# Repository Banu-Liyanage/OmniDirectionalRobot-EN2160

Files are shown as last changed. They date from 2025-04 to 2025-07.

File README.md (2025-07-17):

# 🤖 Omni Directional Robot Platform - EN2160

<div align="center">


<br>
<!-- [![University](https://img.shields.io/badge/University%20of-Moratuwa-red?style=for-the-badge&logo=university&logoColor=white)](https://uom.lk)
[![Course](https://img.shields.io/badge/Course-EN2160-orange?style=for-the-badge&logo=academic&logoColor=white)]()
[![License](https://img.shields.io/badge/License-MIT-green?style=for-the-badge&logo=opensource&logoColor=white)]() -->

</div>

---

## 🌟 Project Vision

**Revolutionizing Indoor Automation Through Intelligent Omnidirectional Mobility**

This repository showcases the design and development of an **Omni Directional Robot Platform** engineered as part of the **EN2160: Electronic Design Realization Module** at the University of Moratuwa. 

Our mission is to create a **highly maneuverable, precise, and intelligent robotic platform** capable of navigating complex indoor environments with ease. 

This project shows how we apply theoretical concepts from electronics and control systems to build a practical solution that meets real-world challenges in automation and robotics.

This is an on-going project, where we are currently working on the Robot's Firmware and Control systems. The hardware is already completed and tested.

<div align="center">
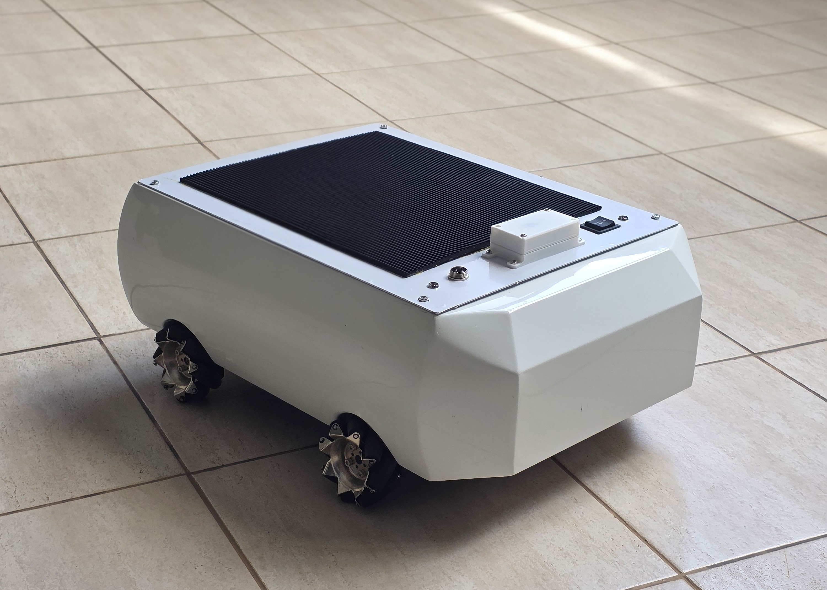
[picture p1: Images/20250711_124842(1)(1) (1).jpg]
  
</div>

---

## 🎯 Project Objectives

<div align="center">

| 🎪 **Mecanum Wheel Kinematics** | 🧠 **Intelligent Positioning** | ⚙️ **Precision Control** |
|:---:|:---:|:---:|
| 4-wheel Mecanum platform for unrestricted motion | Advanced position estimation algorithms | Real-time wheel control with sub-millimeter accuracy |

</div>

---

<!-- ## 🛠️ Revolutionary Features

### 🎯 **Core Capabilities**

| Feature | Description | Status |
|:---:|:---|:---:|
| ✅ **Mecanum Wheel Mastery** | Advanced 4-wheel omnidirectional locomotion system | 🟢 **Complete** |
| ✅ **Multi-MCU Architecture** | Distributed processing with dedicated motor controllers | 🟢 **Complete** |
| ✅ **Precision Sensing Suite** | IMU-based orientation tracking and sensor fusion | 🟢 **Complete** |
| ✅ **Wireless Command Center** | Bluetooth connectivity with intuitive GUI control | 🟢 **Complete** |
| ✅ **Robust Communication** | RS485 differential signaling for noise immunity | 🟢 **Complete** |
| ✅ **Modular PCB Design** | Custom-engineered boards for power, logic, and motor control | 🟢 **Complete** |
| ✅ **Real-Time Diagnostics** | Live telemetry and system health monitoring | 🟢 **Complete** |
| ✅ **Industrial Aesthetics** | Professional-grade chassis with automotive paint finish | 🟢 **Complete** | -->

<div align="center">

<!-- Add feature showcase images here -->

<table>
<tr>
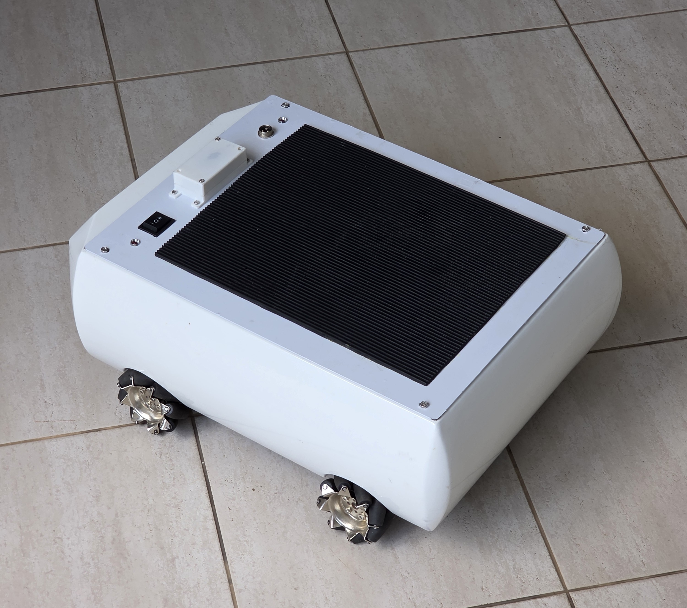
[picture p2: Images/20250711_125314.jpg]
Complete Robot
<td align="center"><br><b>Complete Assembly</b></td>
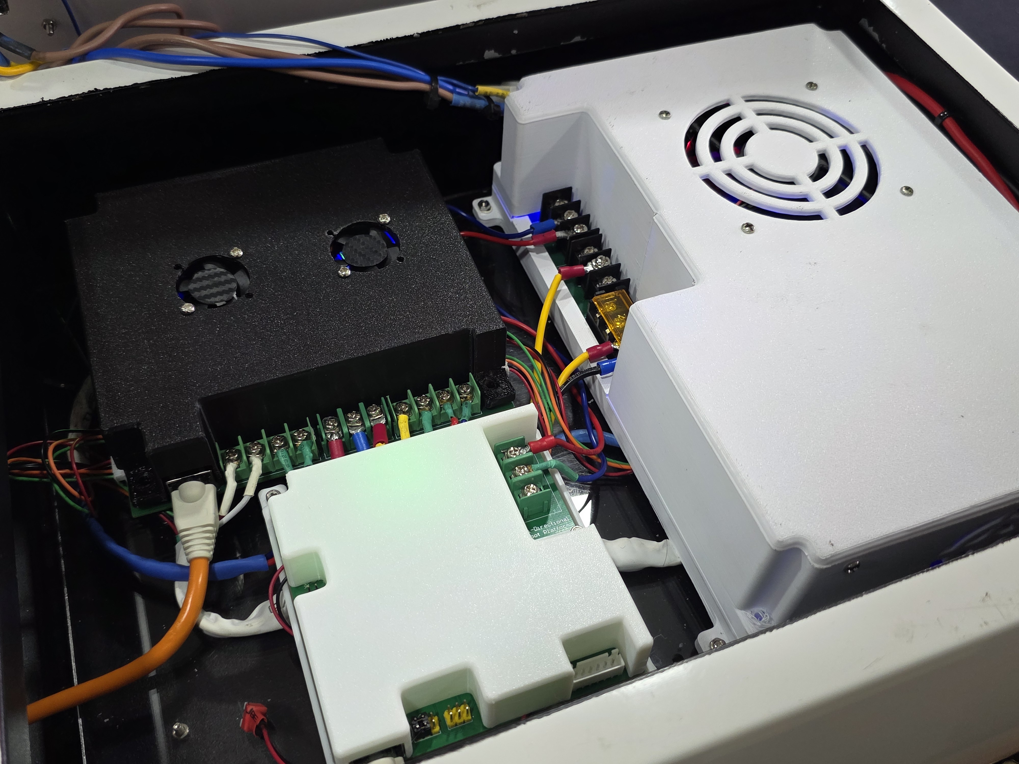
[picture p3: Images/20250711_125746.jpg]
Enclosure
<td align="center"><br><b>Internal view</b></td>

</tr>
</table>

</div>

---

## 🔌 Electronic Systems

<!-- ### 📋 **PCB Module Ecosystem** -->

<div align="center">

<!-- Add PCB images here -->
<table>
<tr>
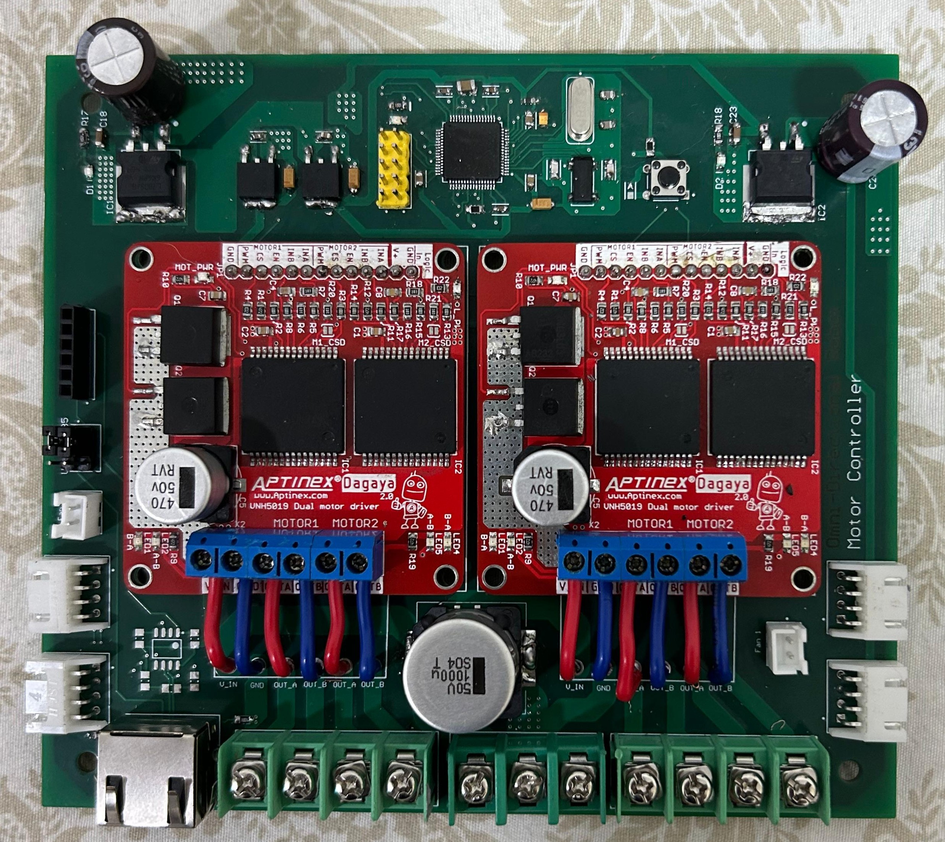
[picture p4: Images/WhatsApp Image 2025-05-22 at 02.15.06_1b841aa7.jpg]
Electronics
<td align="center"><br><b>Motor Controller PCB</b></td>
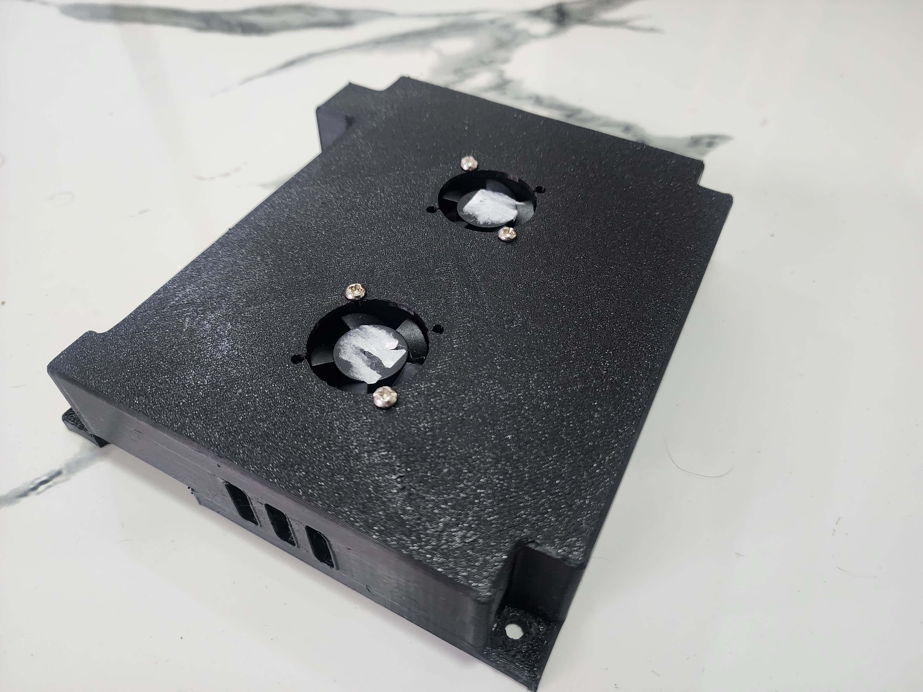
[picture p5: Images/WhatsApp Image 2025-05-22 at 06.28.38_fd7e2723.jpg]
Drive System
<td align="center"><br><b>Motor Controller Enclosure</b></td>

</tr>
<tr>
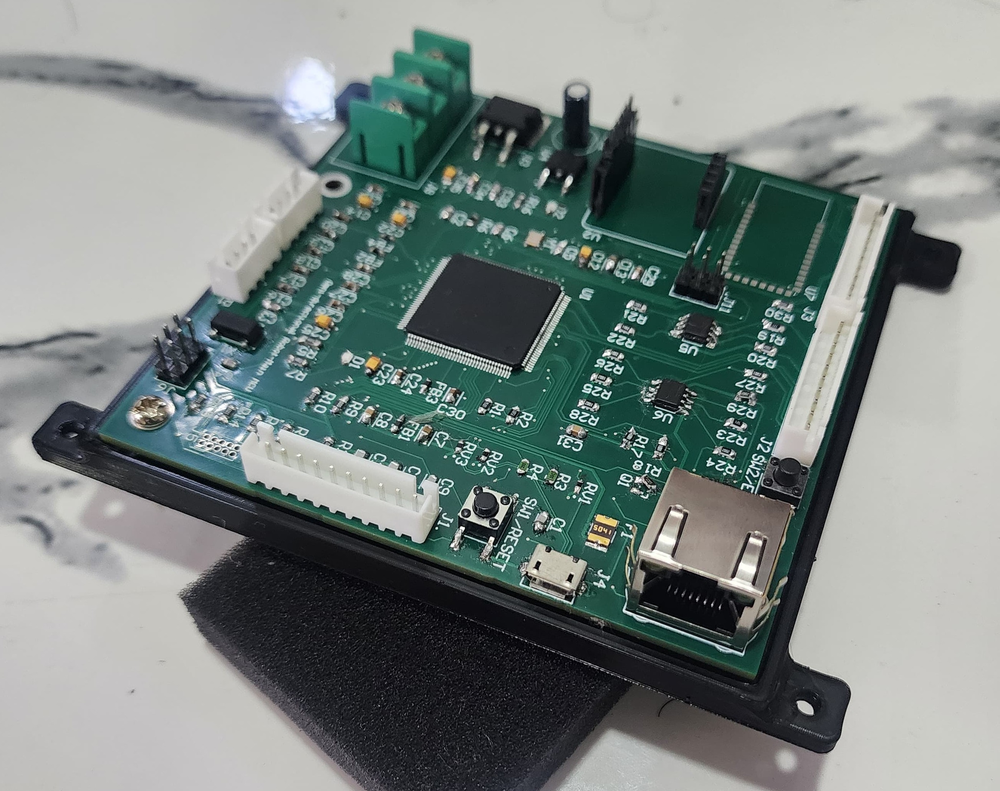
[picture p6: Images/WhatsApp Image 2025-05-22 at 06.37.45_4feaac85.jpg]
Controller
<td align="center"><br><b>Main Controller PCB</b></td>
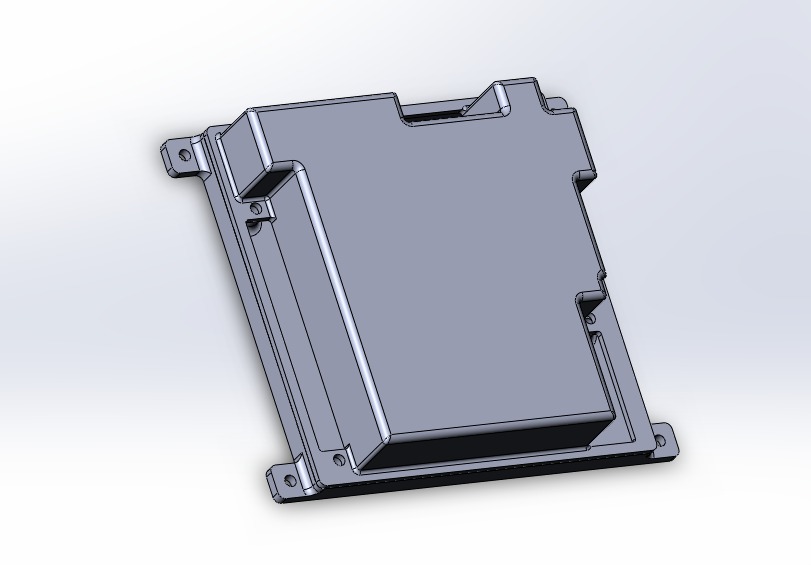
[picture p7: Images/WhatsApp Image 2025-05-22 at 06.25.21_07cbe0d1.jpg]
Motors
<td align="center"><br><b>Main Controller Enclosure</b></td>
</tr>
</table>
</div>

| **PCB Module** | **Function** | **Key Features** |
|:---:|:---|:---|
| 🔋 **Power Distribution** | Multi-rail power management | Fuse protection, LED diagnostics, screw terminals |
| 🧠 **Main Controller** | System coordination and communication | 4-layer design, SAM3X8E, BNO055, HC-05 integration |
| ⚡ **Motor Controller** | Real-time motor drive and feedback | STM32F446RE, VNH5019 drivers, RS485 communication |

<!-- ### 🛡️ **Safety & Protection Systems**

- **20A Master Fuse** with branch-specific protection (2A-15A)
- **Thermal Management** with active cooling consideration
- **Overcurrent Protection** at component and system levels
- **EMI Mitigation** through differential signaling and proper grounding

--- -->

---

### 🏗️ **System Architecture**

<div align="center">

<!-- Add system architecture diagram here -->

</div>

### ⚡ **Hardware Specifications**

| **Component** | **Selection** | **Performance** |
|:---:|:---:|:---:|
| 🧠 **Main MCU** | SAM3X8E | 84 MHz Cortex-M3 |
| 🎮 **Motor Controller** | STM32F446RE | 180 MHz, Real-time loops |
| 🔋 **Drive Motors** | 24V 5Nm Planetary Gear | 1:100 ratio, 120 RPM |
| 🧭 **Navigation IMU** | Bosch BNO055 | 9-DOF sensor fusion |
| ⚡ **Motor Drivers** | VNH5019 H-Bridge | 30A peak current |
| 🎯 **Mecanum Wheels** | Metal-core construction | Omnidirectional mobility |
| 🔌 **Power System** | 12V battery + regulation | Modular distribution |
| 📡 **Communication** | RS485 + Bluetooth HC-05 | Differential + wireless |

<!-- ### 📐 **Mechanical Design**

**Chassis Engineering:**
- **Material:** Stainless steel construction with cantalie sheet vibration dampening
- **Finish:** Automotive-grade paint system for professional appearance
- **Assembly:** In-house fabrication using precision welding and machining
- **Modularity:** 3D printed enclosures for PCB protection and accessibility -->

## 🧠 Intelligence Stack

### 🎛️ **Control Hierarchy**

```mermaid
graph TD
    A[Python GUI Controller] <-->|Bluetooth| B[SAM3X8E Main Controller]
    B <-->|RS485| C[STM32F446RE Motor Controller]
    B <-->|I2C| D[BNO055 IMU]
    C -->|PWM| E[VNH5019 Motor Drivers]
    E --> F[Mecanum Wheels]

```

 ### 🎯 **Software Architecture**

| **Layer** | **Function** | **Technology** |
|:---:|:---|:---:|
| 🖥️ **User Interface** | Intuitive direction control and telemetry | Python Tkinter GUI |
| 📡 **Communication** | Wireless command transmission and echo verification | Bluetooth Serial Protocol |
| 🧠 **High-Level Control** | Command parsing, sensor fusion, system coordination | SAM3X8E Embedded C++ |
| ⚡ **Real-Time Control** | PWM generation, encoder processing, motor loops | STM32 Real-Time OS |
| 🔧 **Hardware Abstraction** | Driver interfaces and peripheral management | HAL Libraries | -->

---

<!-- ## 📊 Performance Metrics

<div align="center">

### 🏆 **Benchmark Results**

</div>

| **Metric** | **Specification** | **Achievement** |
|:---:|:---:|:---:|
| 🏋️ **Payload Capacity** | 5 kg operational load | **✅ Exceeded** |
| ⚖️ **Total System Weight** | ~25 kg including payload | **✅ Target Met** |
| 🔧 **Wheel Torque** | 3.2 Nm per wheel minimum | **✅ Optimized** |
| 🚀 **Maximum Speed** | 1 m/s target velocity | **✅ Achieved** |
| 🎯 **Positioning Accuracy** | Sub-millimeter precision | **✅ Validated** |
| 📡 **Communication Range** | 10m+ Bluetooth connectivity | **✅ Confirmed** |
| ⚡ **Response Time** | <50ms command to motion | **✅ Real-Time** | -->

---

## 🧱 Mechanical Design & FEA Analysis

<!-- <div align="left">

### *Robust Engineering for Real-World Demands*

</div> -->

The mechanical design of the platform was optimized for both **structural integrity** and **functional adaptability**, with a focus on durability, vibration mitigation, and payload endurance.

### 🛠️ Structural Overview

- **Material Selection:** Stainless steel box bars with cantalie vibration dampening
- **Fabrication:** In-house welding, precision machining, and 3D printed PCB enclosures
- **Design Philosophy:** Balancing rigidity and modularity for both performance and ease of maintenance

### 📊 FEA Validation

Extensive Finite Element Analysis (FEA) was conducted to validate:

- Load-bearing capacity under dynamic and static conditions
- Results depicts chassis has a 900% safe margin
- Stress and deformation distribution across the chassis
- Vibration response under high-speed operation

<div align="center">

<table>
<tr>
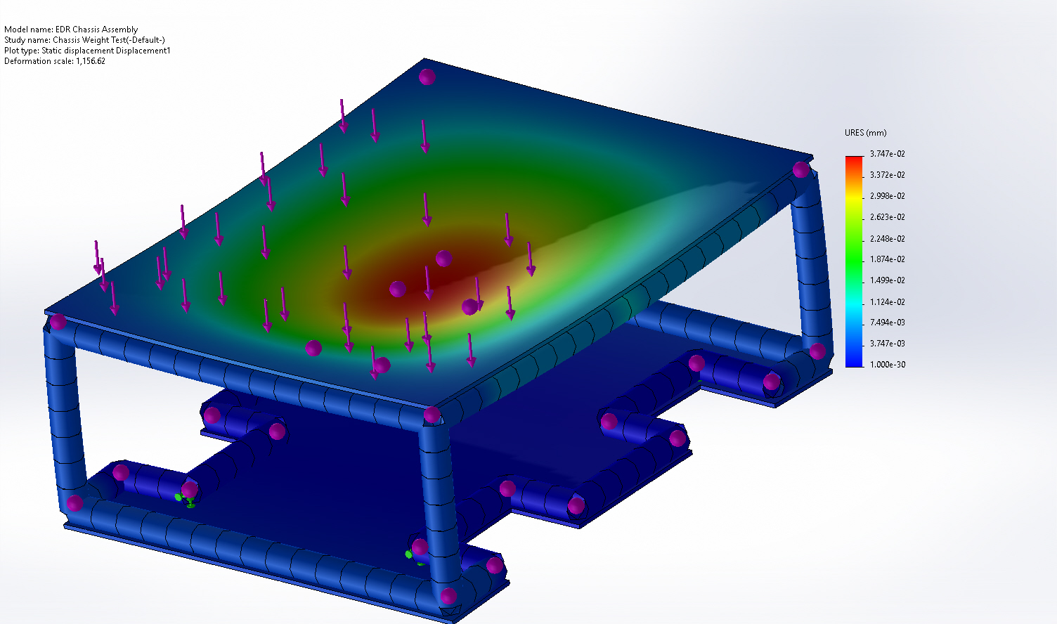
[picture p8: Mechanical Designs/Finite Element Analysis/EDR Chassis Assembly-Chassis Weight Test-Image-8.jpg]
CAD Model
<td align="center"><br><b>CAD Model of Chassis</b></td>
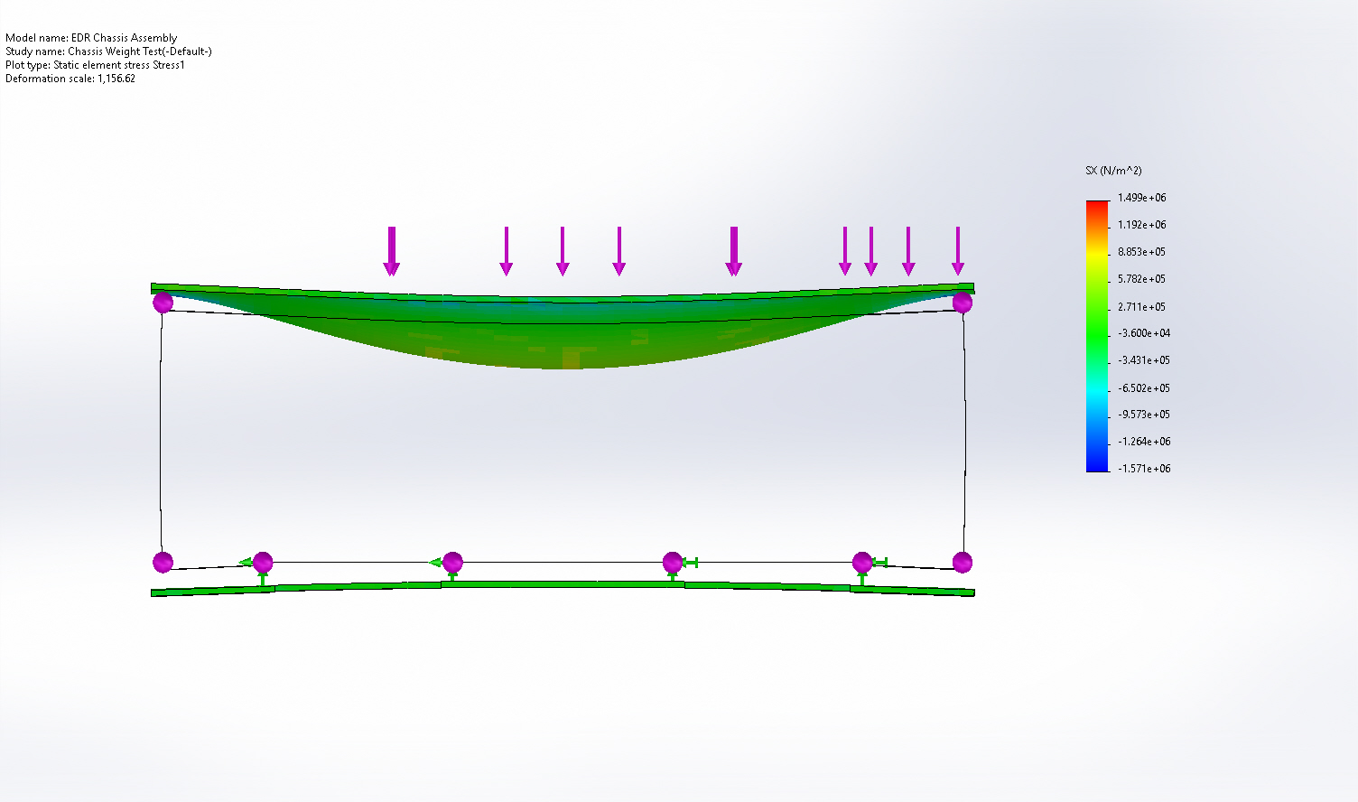
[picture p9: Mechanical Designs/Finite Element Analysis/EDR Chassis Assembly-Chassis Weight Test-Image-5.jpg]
FEA Analysis
<td align="center"><br><b>FEA Stress Distribution</b></td>
</tr>
</table>

</div>

---

## 🚀 Applications & Use Cases

<!-- <div align="center">

*Transforming Industries Through Intelligent Mobility*

</div> -->

| 🏭 **Industrial** | 🏥 **Healthcare** | 🛒 **Retail** | 🎓 **Education** |
|:---:|:---:|:---:|:---:|
| Logistics automation | Hospital transport | Inventory management | Research platform |
| Material handling | Supply delivery | Shelf restocking | STEM demonstrations |
| Quality inspection | Patient assistance | Customer guidance | Competition robotics |

---

## 👥 Team

<div align="center">

| 🧑‍💻 **Name** | 📧 **Email** |
|:---:|:---:|
| **Pankaja Balasooriya** | balasooriyabapi.22@uom.lk |
| **Oshani Dewasumithra** | dewasumithrampo.22@uom.lk |
| **Chandupa Dineshara** | dinesharamc.22@uom.lk |
| **Chamath Diunugala** | diunugalach.22@uom.lk |
| **Sahas Eshan** | eashansgs.22@uom.lk |
| **Rusiru Fernando** | fernandoard.22@uom.lk |
| **Banuka Liyanage** | liyanagedlbb.22@uom.lk |
| **Rusula Oshadha Pathirana** | pathiranapdro.22@uom.lk |

</div>
<div align="center">
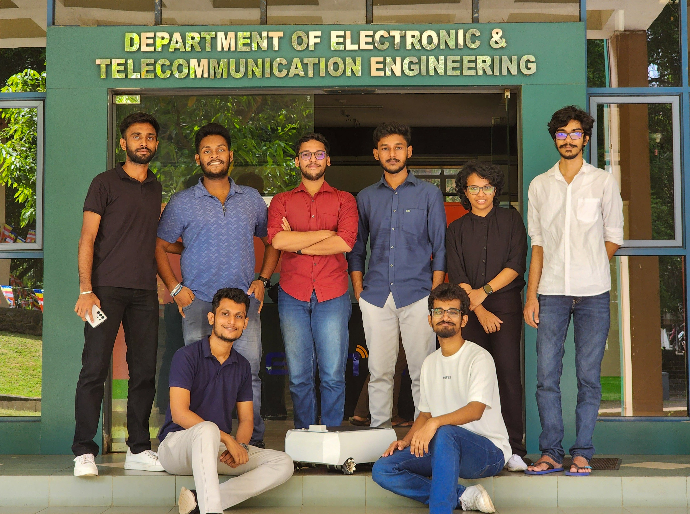
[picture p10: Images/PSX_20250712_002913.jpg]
  
</div>

<!-- ## 📁 Repository Architecture

```
OmniDirectionalRobot-EN2160/
├── 📁 firmware/              # Embedded systems code
│   ├── main_controller/      # SAM3X8E firmware
│   ├── motor_controller/     # STM32F446RE code  
│   └── libraries/           # Custom libraries and drivers
├── 📁 hardware/              # Electronic design files
│   ├── pcb_designs/         # KiCad/Altium schematics and layouts
│   ├── mechanical/          # CAD files and drawings
│   └── datasheets/          # Component specifications
├── 📁 software/              # High-level software
│   ├── gui_controller/      # Python Tkinter interface
│   ├── simulation/          # Motion simulation tools
│   └── utilities/           # Testing and calibration scripts
├── 📁 docs/                  # Comprehensive documentation
│   ├── design_reports/      # Technical documentation
│   ├── user_manual/         # Operation guidelines
│   └── api_reference/       # Software interfaces
├── 📁 media/                 # Visual assets
│   ├── images/              # Photos and diagrams
│   ├── videos/              # Demonstration footage
│   └── presentations/       # Project presentations
├── 📁 tests/                 # Validation and testing
│   ├── unit_tests/          # Component-level tests
│   ├── integration_tests/   # System-level validation
│   └── performance_data/    # Benchmark results
└── 📁 resources/            # Additional materials
    ├── references/          # Academic papers and standards
    └── tools/               # Development utilities
```

--- -->

<!-- ## 🌐 Future Roadmap

### 🔮 **Next-Generation Enhancements**

| **Phase** | **Enhancement** | **Impact** | **Timeline** |
|:---:|:---|:---|:---:|
| 🔋 **Phase 1** | Advanced Battery Management System | Extended operational time | Q2 2025 |
| 🤖 **Phase 2** | Autonomous Navigation & SLAM | Self-directed operation | Q3 2025 |
| 🌐 **Phase 3** | ROS2 Integration & Fleet Management | Multi-robot coordination | Q4 2025 |
| 🧠 **Phase 4** | AI-Powered Decision Making | Intelligent task execution | Q1 2026 |
| 📡 **Phase 5** | Cloud Analytics Dashboard | Remote monitoring and optimization | Q2 2026 |

--- -->

<!-- ## 🏆 Project Impact

<div align="center">

### *Engineering Excellence Recognition*

</div>

This project demonstrates how **academic excellence** can drive **industry innovation**. By combining theoretical knowledge with practical implementation, we've created a platform that bridges the gap between education and real-world applications.

**Key Contributions:**
- Advanced undergraduate-level robotics engineering
- Open-source platform for educational advancement  
- Industry-applicable design methodologies
- Sustainable and cost-effective innovation -->

<!-- ---

## 📞 Connect With Us

<div align="center">

### *Join the Robotics Revolution*

[![Email](https://img.shields.io/badge/Email-Team%20Contact-red?style=for-the-badge&logo=gmail&logoColor=white)](mailto:robotics.en2160@uom.lk)
[![LinkedIn](https://img.shields.io/badge/LinkedIn-University%20of%20Moratuwa-blue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)](https://linkedin.com/school/university-of-moratuwa)
[![YouTube](https://img.shields.io/badge/YouTube-Project%20Demos-red?style=for-the-badge&logo=youtube&logoColor=white)](https://youtube.com/@UoMRobotics)
[![GitHub](https://img.shields.io/badge/GitHub-Open%20Source-black?style=for-the-badge&logo=github&logoColor=white)](https://github.com/UoM-Robotics)

</div>

---

## 📄 Documentation & Resources

| **Document** | **Description** | **Access** |
|:---:|:---|:---:|
| 📋 **Technical Specifications** | Detailed system parameters and performance data | [📖 View](docs/specifications.md) |
| 🔧 **Assembly Guide** | Step-by-step construction instructions | [🛠️ Guide](docs/assembly_guide.md) |
| 💻 **Software Manual** | Programming interfaces and API documentation | [💾 Manual](docs/software_manual.md) |
| 🎥 **Video Demonstrations** | Live operation footage and feature showcases | [🎬 Watch](media/videos/) |
| 📊 **Performance Analysis** | Testing results and benchmark comparisons | [📈 Data](tests/performance_data/) | -->

---

<!-- ## 🙏 Acknowledgments

<!-- <div align="center">

*Standing on the Shoulders of Giants*

</div> -->

<!-- We extend our deepest gratitude to:

- **University of Moratuwa** - For providing world-class engineering education and facilities
- **Department of Electronic and Telecommunication Engineering** - For academic guidance and resources  
- **EN2160 Course Instructors** - For mentorship and technical expertise
- **Industry Partners** - For component support and technical consultation
- **Open Source Community** - For foundational libraries and inspiration

---  -->
<!-- 
## 📜 License & Usage

This project is released under the **MIT License**, promoting open innovation and educational advancement. We encourage the global robotics community to build upon our work, contribute improvements, and push the boundaries of autonomous mobile robotics.

```
MIT License - Open Innovation for Global Impact
Copyright (c) 2024 University of Moratuwa Robotics Team
``` -->

<!-- ---

<div align="center">

### 🌟 **"Innovation Distinguished by Excellence"** 🌟

*Crafted with passion by the future engineers of tomorrow*

**University of Moratuwa | Department of Electronic and Telecommunication Engineering**

--- -->
<div align="center">
Made with ❤️ in Sri Lanka

Department of Electronic and Telecommunication Engineering 

University of Moratuwa

</div>

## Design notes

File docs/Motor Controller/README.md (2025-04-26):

https://control.com/technical-articles/in-introduction-to-types-of-closed-loop-motor-control/
https://circuitglobe.com/closed-loop-control-of-drives.html
https://www.eeeguide.com/closed-loop-torque-control-of-drives/

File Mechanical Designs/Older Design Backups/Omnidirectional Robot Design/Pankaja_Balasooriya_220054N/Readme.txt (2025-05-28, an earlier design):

All the molds are hidden in both assembly and parts.

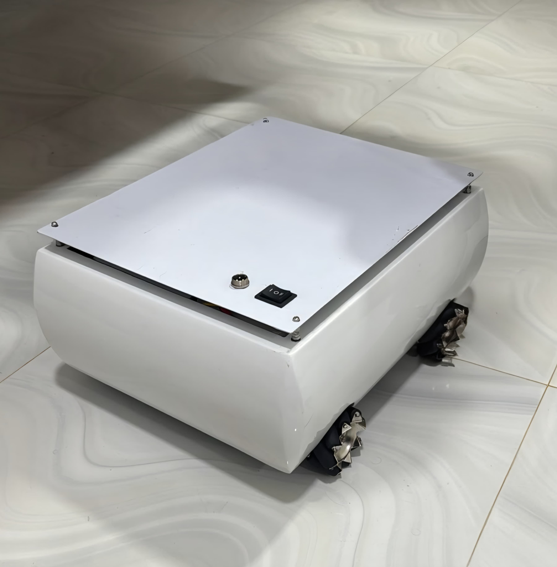
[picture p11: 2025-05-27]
Images/robot.jpg

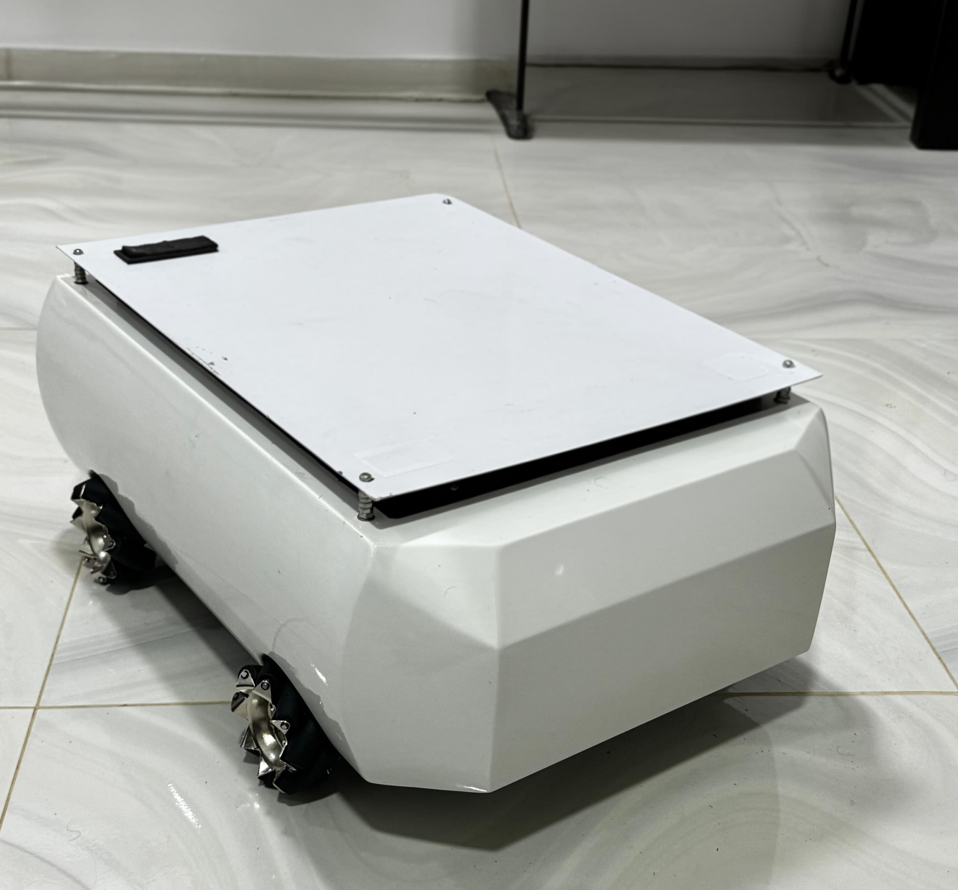
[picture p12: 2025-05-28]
Images/front.jpg

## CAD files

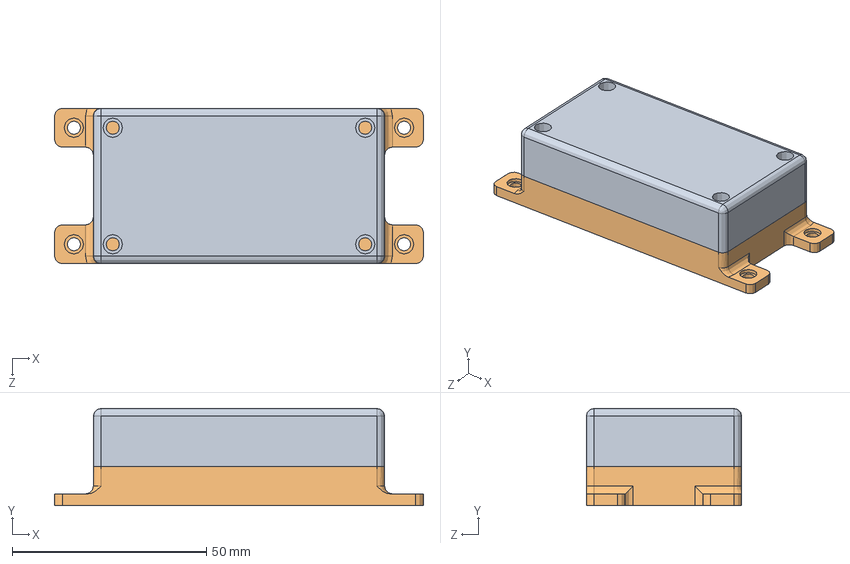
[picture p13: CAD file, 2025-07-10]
Mechanical Designs/Files for Fabrication/PCB enclosures/IMU enclosure.SLDASM
95.0 x 25.0 x 40.0 mm
top2
bottom

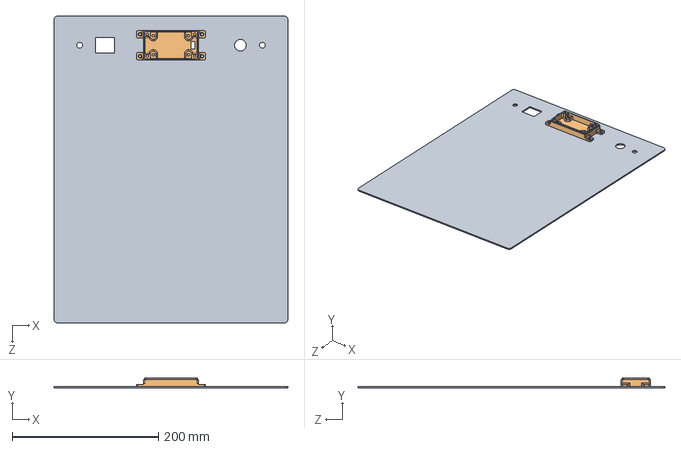
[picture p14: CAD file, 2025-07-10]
Mechanical Designs/Files for Fabrication/Top_plate_v2.0/Top plate assembly.SLDASM
320.0 x 14.0 x 420.0 mm
Top_plate_v2.0
IMU bottom

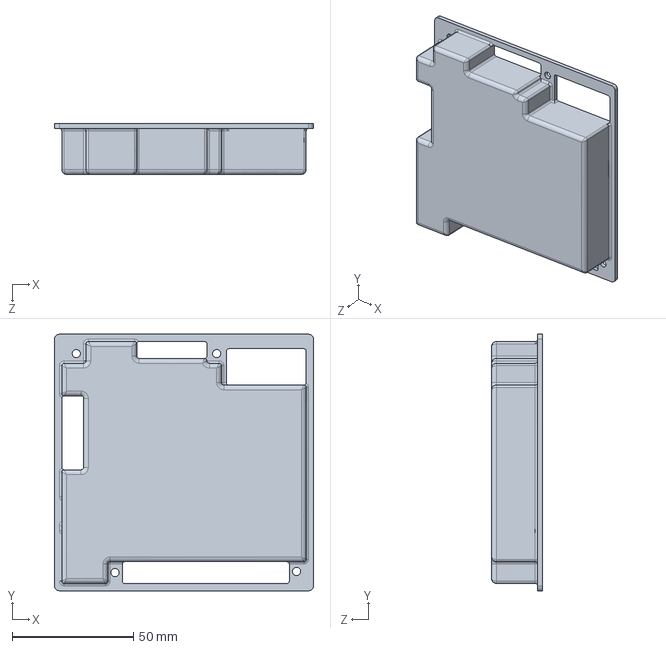
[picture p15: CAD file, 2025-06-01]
Mechanical Designs/Files for Fabrication/PCB enclosures/Main PCB enclosure Top.SLDPRT
107.0 x 106.0 x 21.0 mm

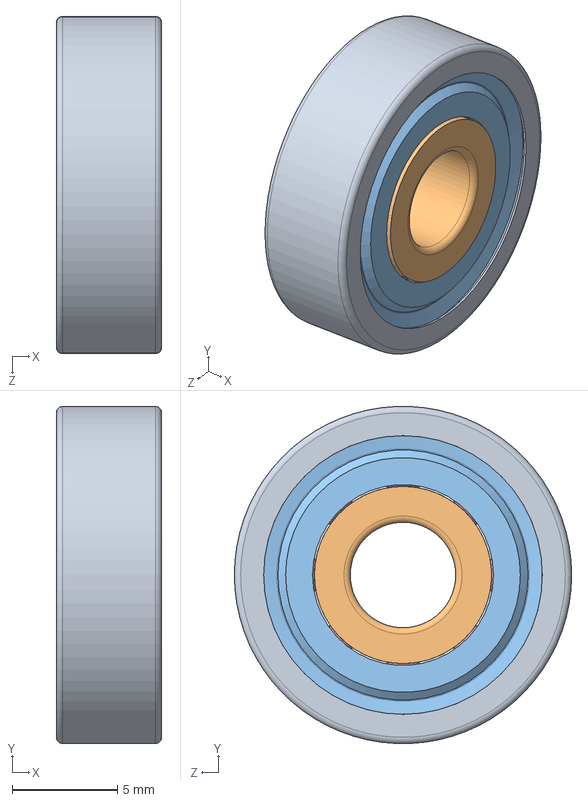
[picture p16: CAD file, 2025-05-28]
Mechanical Designs/EDR Chassis Assembly/roulement_625-2z_2.SLDASM
5.00 x 16.0 x 16.0 mm
roulement_625-2z_2_01
roulement_625-2z_2_02
roulement_625-2z_2_03
roulement_625-2z_2_04
roulement_625-2z_2_05

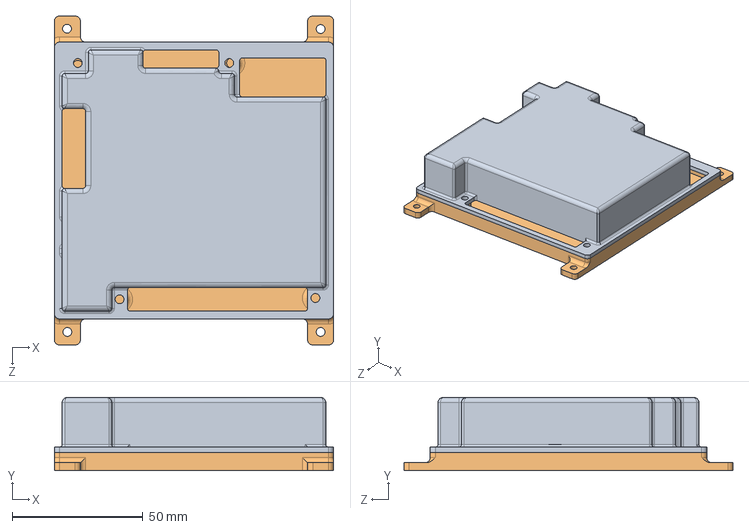
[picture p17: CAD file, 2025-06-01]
Mechanical Designs/Files for Fabrication/PCB enclosures/Main PCB enclosure.SLDASM
107.0 x 28.0 x 126.0 mm
MCU top
base

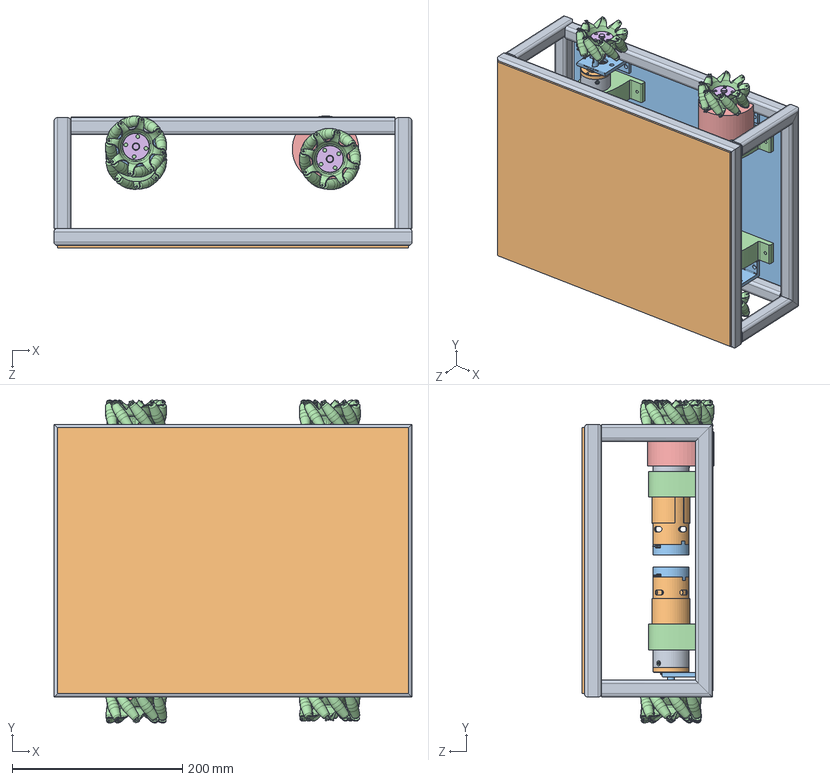
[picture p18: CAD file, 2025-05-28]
Mechanical Designs/EDR Chassis Assembly/EDR Chassis Assembly.SLDASM
420.0 x 378.6 x 155.0 mm
Box bar frame
Top Plate
Bottom Plate
Motor Mount x 4
retaining-ring_3cm1-8 x 4
(24300)M3x6 x 20
roulement_628_8-2z_2_01 x 4
roulement_628_8-2z_2_02 x 4
roulement_628_8-2z_2_03 x 4
roulement_628_8-2z_2_04 x 4
roulement_628_8-2z_2_05 x 4
roulement_625-2z_2_01 x 4
roulement_625-2z_2_02 x 4
roulement_625-2z_2_03 x 4
roulement_625-2z_2_04 x 4
roulement_625-2z_2_05 x 4
L brackets x 4
Macenum Wheel x 3
Coupler front x 3
Coupler back x 3

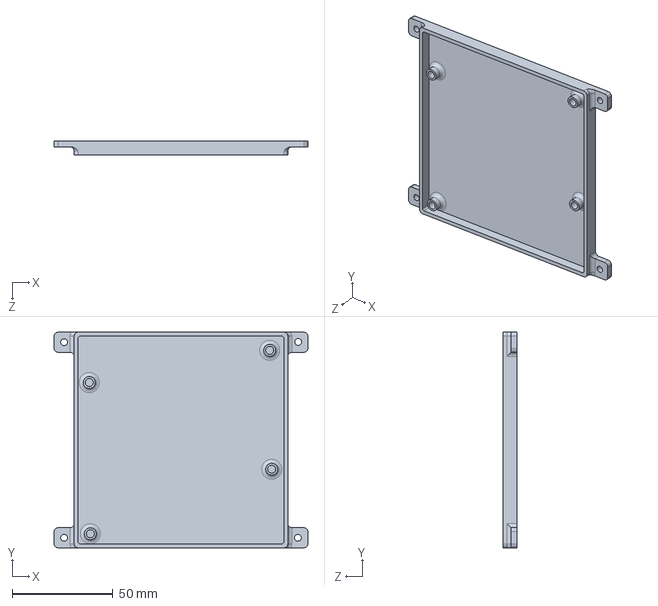
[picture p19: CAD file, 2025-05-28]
Mechanical Designs/Files for Fabrication/PCB enclosures/Main PCB enclosure Bottom.SLDPRT
126.0 x 107.0 x 7.00 mm

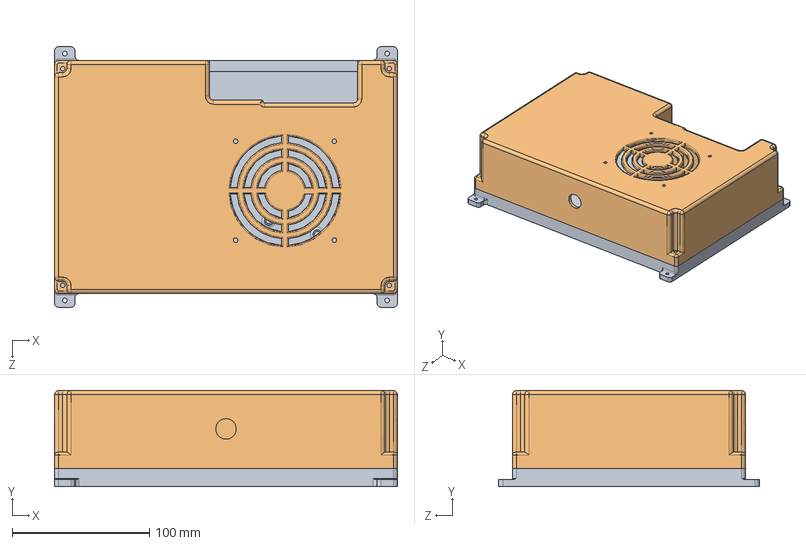
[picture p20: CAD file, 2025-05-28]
Mechanical Designs/Files for Fabrication/PCB enclosures/Power supply PCB enclosure.SLDASM
250.0 x 70.0 x 190.0 mm
power supply base
power supply top

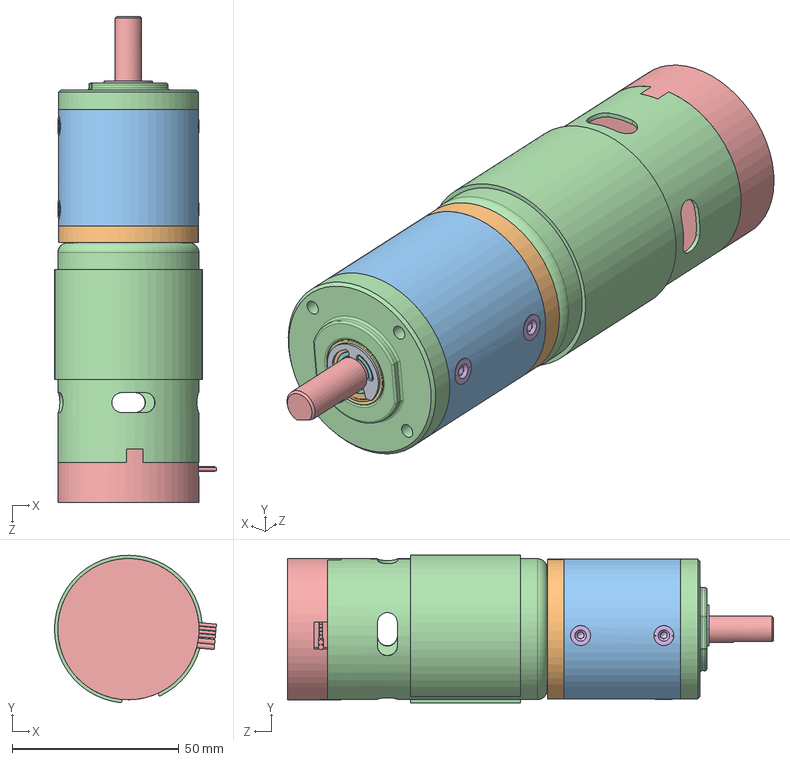
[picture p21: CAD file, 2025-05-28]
Mechanical Designs/EDR Chassis Assembly/IG42-24(1,49).SLDASM
48.6 x 44.3 x 145.9 mm
retaining-ring_3cm1-8
(24300)M3x6 x 5
roulement_628_8-2z_2_01
roulement_628_8-2z_2_02
roulement_628_8-2z_2_03
roulement_628_8-2z_2_04
roulement_628_8-2z_2_05
roulement_625-2z_2_01
roulement_625-2z_2_02
roulement_625-2z_2_03
roulement_625-2z_2_04
roulement_625-2z_2_05

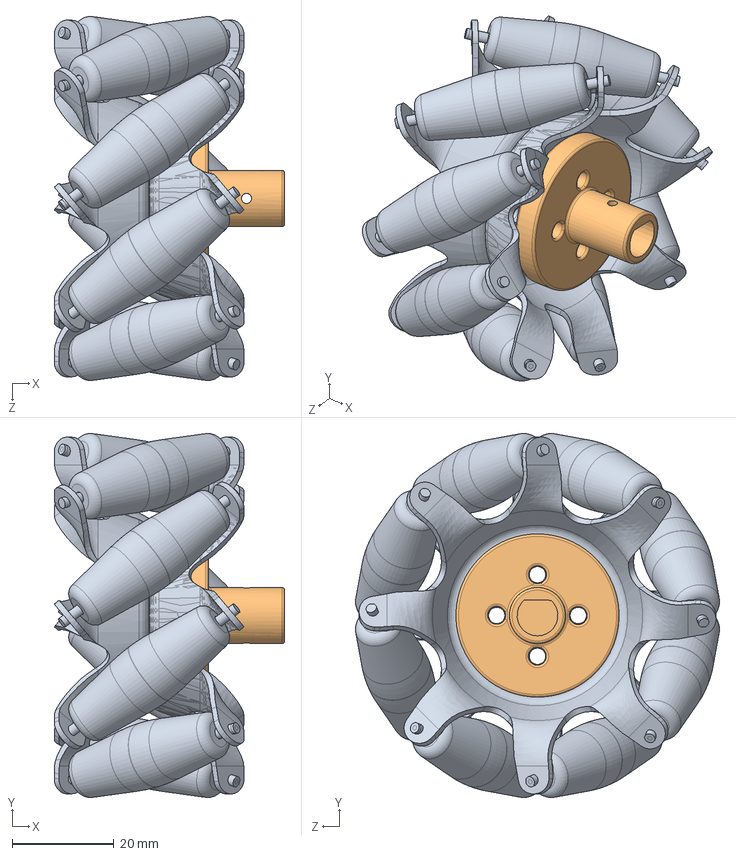
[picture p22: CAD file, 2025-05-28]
Mechanical Designs/EDR Chassis Assembly/Macenum wheel couplers.SLDASM
45.2 x 71.4 x 71.4 mm
Macenum Wheel
Coupler front
Coupler back

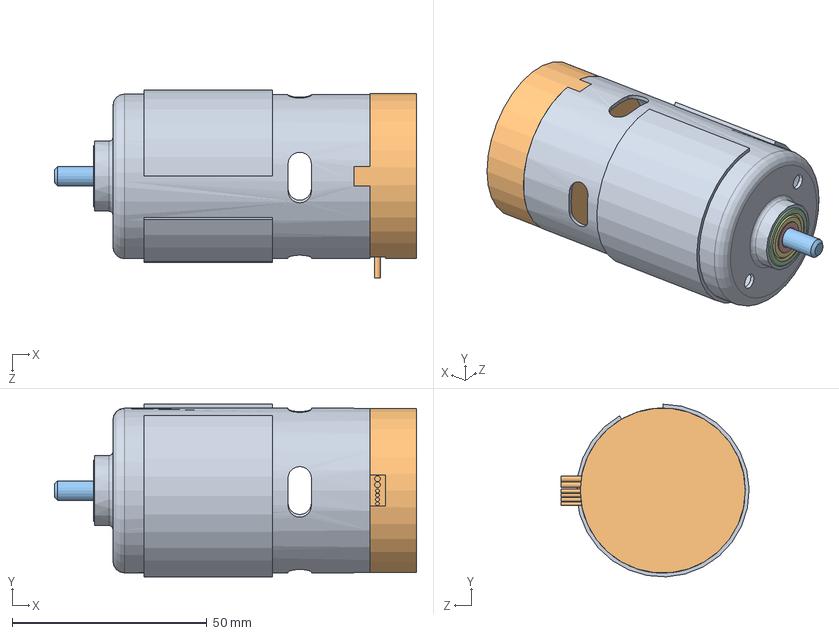
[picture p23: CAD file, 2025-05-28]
Mechanical Designs/EDR Chassis Assembly/IG42,PG420,MG49 DC Motor.SLDASM
93.0 x 44.4 x 48.4 mm
roulement_625-2z_2_01
roulement_625-2z_2_02
roulement_625-2z_2_03
roulement_625-2z_2_04
roulement_625-2z_2_05

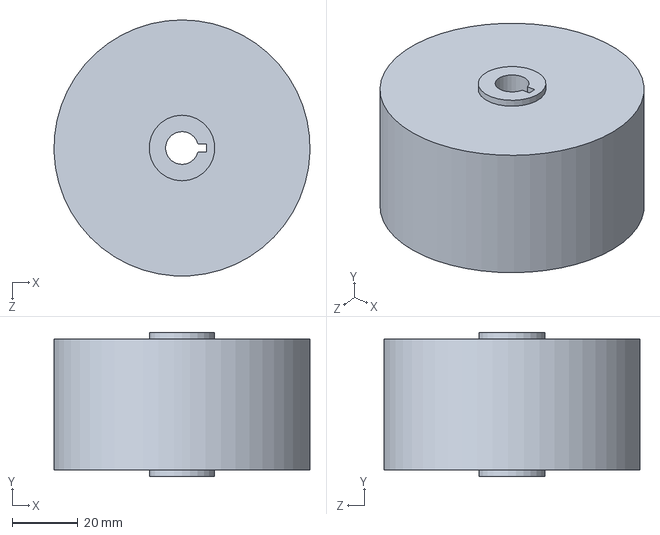
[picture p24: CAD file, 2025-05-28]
Mechanical Designs/EDR Chassis Assembly/Wheel.SLDPRT
78.0 x 44.0 x 78.0 mm

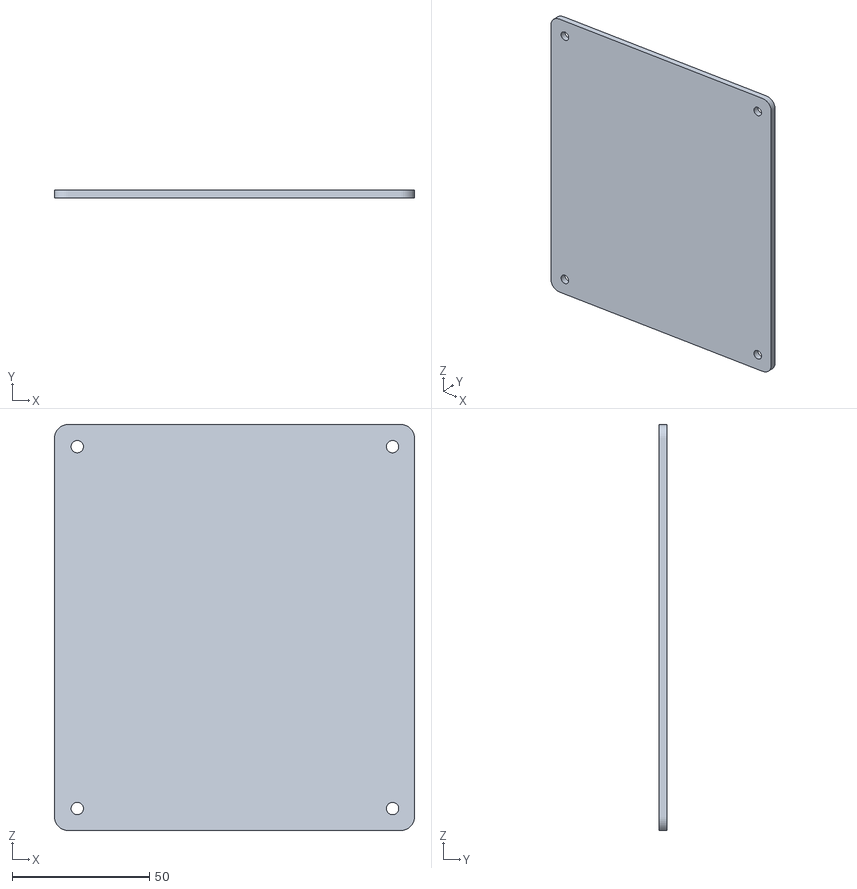
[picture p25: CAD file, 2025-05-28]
Mechanical Designs/Files for Fabrication/3D Prints/Motor controller bottom plate.STL
131.3 x 3.00 x 148.1

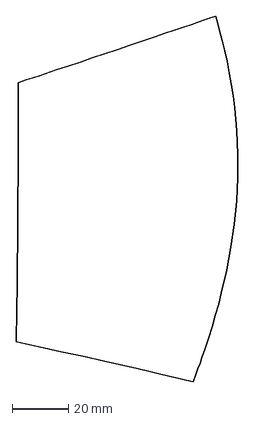
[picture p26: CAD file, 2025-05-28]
Mechanical Designs/Files for Fabrication/CNC files/Front 11.DXF
79.1 x 129.9 mm

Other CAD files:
Mechanical Designs/EDR Chassis Assembly/roulement_628_8-2z_2.SLDASM
Mechanical Designs/Files for Fabrication/PCB enclosures/IMU bottom.SLDPRT
Mechanical Designs/Files for Fabrication/Sheet Metal Works for Face/Front 8.DXF
Mechanical Designs/Files for Fabrication/Support Files/Bottom plate cutting support.SLDPRT
Mechanical Designs/EDR Chassis Assembly/(24300)M3x6.SLDPRT
Mechanical Designs/EDR Chassis Assembly/1.SLDPRT
Mechanical Designs/EDR Chassis Assembly/2.SLDPRT
Mechanical Designs/EDR Chassis Assembly/3.SLDPRT
Mechanical Designs/EDR Chassis Assembly/4.SLDPRT
Mechanical Designs/EDR Chassis Assembly/Besring mount.SLDPRT
Mechanical Designs/EDR Chassis Assembly/Bottom Plate.SLDPRT
Mechanical Designs/EDR Chassis Assembly/Box bar frame.SLDPRT
Mechanical Designs/EDR Chassis Assembly/Coupler back.SLDPRT
Mechanical Designs/EDR Chassis Assembly/Coupler front.SLDPRT
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

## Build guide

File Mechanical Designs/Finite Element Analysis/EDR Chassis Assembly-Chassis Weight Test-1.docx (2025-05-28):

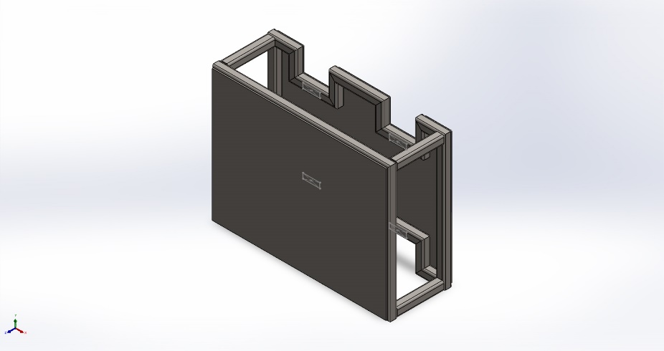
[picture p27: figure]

Simulation of EDR Chassis Assembly

Date: Wednesday, April 2, 2025
Designer: Omni-Directional Robot

Study name: Chassis Weight Test

Analysis type: Static
Description No Data

# Assumptions

# Model Information

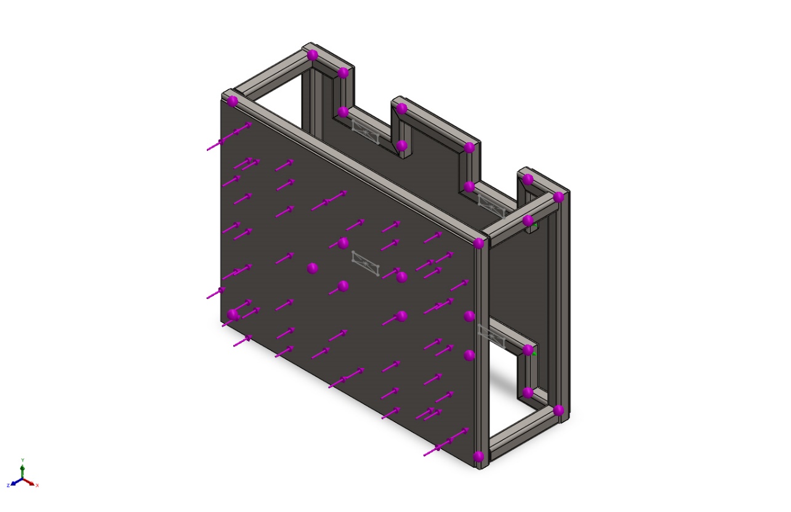
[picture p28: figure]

Model name: EDR Chassis Assembly

Current Configuration: Default

Solid Bodies
Document Name and Reference | Treated As | Volumetric Properties | Document Path/Date Modified

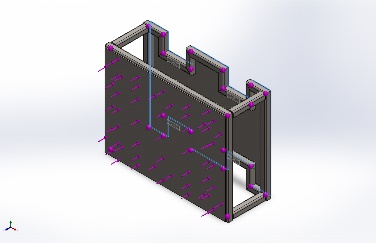
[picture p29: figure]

Boss-Extrude1 | Solid Body | Mass:2.55242 kg Volume:0.000324818 m^3 Density:7,858 kg/m^3 Weight:25.0137 N | C:\Users\USER\Desktop\Chassis Design\Bottom Plate.SLDPRT Apr 1 23:50:49 2025
Boss-Extrude1 | Solid Body | Mass:3.0303 kg Volume:0.000385632 m^3 Density:7,858 kg/m^3 Weight:29.6969 N | C:\Users\USER\Desktop\Chassis Design\Top Plate.SLDPRT Apr 1 23:50:49 2025

Beam Bodies:
Document Name and Reference | Formulation | Properties | Document Path/Date Modified

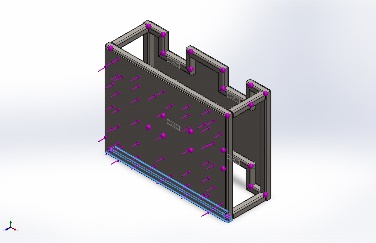
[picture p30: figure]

SolidBody 1(Trim/Extend14[2]) | Beam – Uniform C/S | Section Standard-weldment profiles/iso/square tube Section Area: 0.000133699m^2 Length:400mm Volume:5.34806e-05m^3 Mass Density:7,858kg/m^3 Mass:0.420251kg Weight:4.11846N | C:\Users\USER\Desktop\Chassis Design\Box bar frame.SLDPRT Apr 1 23:41:29 2025
SolidBody 2(Trim/Extend19[2]) | Beam – Uniform C/S | Section Standard-weldment profiles/iso/square tube Section Area: 0.000133699m^2 Length:60.0036mm Volume:8.02257e-06m^3 Mass Density:7,858kg/m^3 Mass:0.0630413kg Weight:0.617805N | C:\Users\USER\Desktop\Chassis Design\Box bar frame.SLDPRT Apr 1 23:41:29 2025

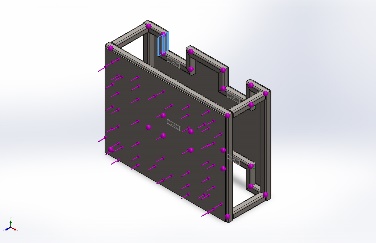
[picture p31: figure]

SolidBody 3(Trim/Extend5[1]) | Beam – Uniform C/S | Section Standard-weldment profiles/iso/square tube Section Area: 0.000133699m^2 Length:55mm Volume:7.35358e-06m^3 Mass Density:7,858kg/m^3 Mass:0.0577845kg Weight:0.566288N | C:\Users\USER\Desktop\Chassis Design\Box bar frame.SLDPRT Apr 1 23:41:29 2025

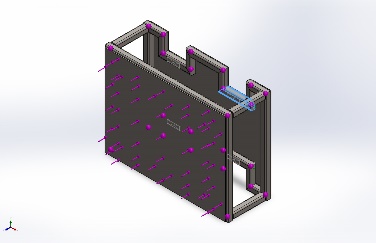
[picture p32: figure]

SolidBody 4(Trim/Extend22[1]) | Beam – Uniform C/S | Section Standard-weldment profiles/iso/square tube Section Area: 0.000133699m^2 Length:95mm Volume:1.27016e-05m^3 Mass Density:7,858kg/m^3 Mass:0.0998095kg Weight:0.978133N | C:\Users\USER\Desktop\Chassis Design\Box bar frame.SLDPRT Apr 1 23:41:29 2025
SolidBody 5(Trim/Extend20[2]) | Beam – Uniform C/S | Section Standard-weldment profiles/iso/square tube Section Area: 0.000133699m^2 Length:55mm Volume:7.35358e-06m^3 Mass Density:7,858kg/m^3 Mass:0.0577845kg Weight:0.566288N | C:\Users\USER\Desktop\Chassis Design\Box bar frame.SLDPRT Apr 1 23:41:29 2025

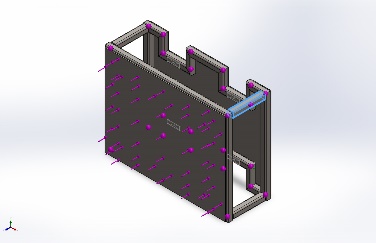
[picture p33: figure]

SolidBody 6(Square tube - configured 20 X 20 X 2(1)[24]) | Beam – Uniform C/S | Section Standard-weldment profiles/iso/square tube Section Area: 0.000133699m^2 Length:110mm Volume:1.47069e-05m^3 Mass Density:7,858kg/m^3 Mass:0.115567kg Weight:1.13256N | C:\Users\USER\Desktop\Chassis Design\Box bar frame.SLDPRT Apr 1 23:41:29 2025

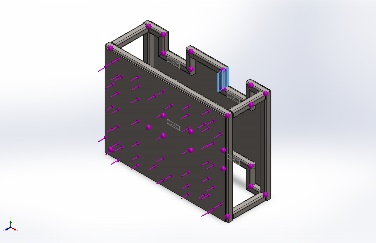
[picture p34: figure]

SolidBody 7(Trim/Extend23[2]) | Beam – Uniform C/S | Section Standard-weldment profiles/iso/square tube Section Area: 0.000133699m^2 Length:55mm Volume:7.35358e-06m^3 Mass Density:7,858kg/m^3 Mass:0.0577845kg Weight:0.566288N | C:\Users\USER\Desktop\Chassis Design\Box bar frame.SLDPRT Apr 1 23:41:29 2025
SolidBody 8(Trim/Extend14[1]) | Beam – Uniform C/S | Section Standard-weldment profiles/iso/square tube Section Area: 0.000133699m^2 Length:300mm Volume:4.01105e-05m^3 Mass Density:7,858kg/m^3 Mass:0.315188kg Weight:3.08884N | C:\Users\USER\Desktop\Chassis Design\Box bar frame.SLDPRT Apr 1 23:41:29 2025

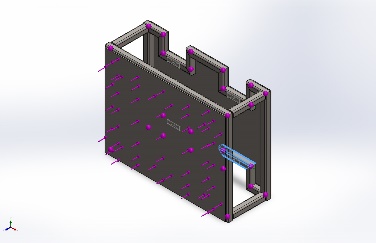
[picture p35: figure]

SolidBody 9(Trim/Extend8[1]) | Beam – Uniform C/S | Section Standard-weldment profiles/iso/square tube Section Area: 0.000133699m^2 Length:95mm Volume:1.27016e-05m^3 Mass Density:7,858kg/m^3 Mass:0.0998095kg Weight:0.978133N | C:\Users\USER\Desktop\Chassis Design\Box bar frame.SLDPRT Apr 1 23:41:29 2025
SolidBody 10(Trim/Extend20[1]) | Beam – Uniform C/S | Section Standard-weldment profiles/iso/square tube Section Area: 0.000133699m^2 Length:110mm Volume:1.47072e-05m^3 Mass Density:7,858kg/m^3 Mass:0.115569kg Weight:1.13258N | C:\Users\USER\Desktop\Chassis Design\Box bar frame.SLDPRT Apr 1 23:41:29 2025

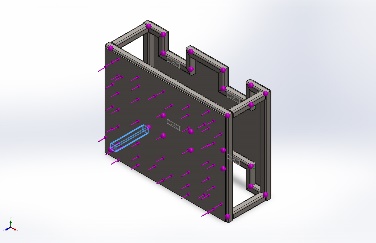
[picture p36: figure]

SolidBody 11(Square tube - configured 20 X 20 X 2(1)[26]) | Beam – Uniform C/S | Section Standard-weldment profiles/iso/square tube Section Area: 0.000133699m^2 Length:110mm Volume:1.47069e-05m^3 Mass Density:7,858kg/m^3 Mass:0.115567kg Weight:1.13256N | C:\Users\USER\Desktop\Chassis Design\Box bar frame.SLDPRT Apr 1 23:41:29 2025

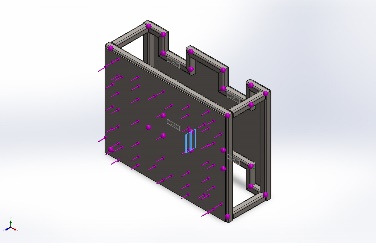
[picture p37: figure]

SolidBody 12(Trim/Extend18[1]) | Beam – Uniform C/S | Section Standard-weldment profiles/iso/square tube Section Area: 0.000133699m^2 Length:55mm Volume:7.35358e-06m^3 Mass Density:7,858kg/m^3 Mass:0.0577845kg Weight:0.566288N | C:\Users\USER\Desktop\Chassis Design\Box bar frame.SLDPRT Apr 1 23:41:29 2025
SolidBody 13(Trim/Extend16[2]) | Beam – Uniform C/S | Section Standard-weldment profiles/iso/square tube Section Area: 0.000133699m^2 Length:400mm Volume:5.34806e-05m^3 Mass Density:7,858kg/m^3 Mass:0.420251kg Weight:4.11846N | C:\Users\USER\Desktop\Chassis Design\Box bar frame.SLDPRT Apr 1 23:41:29 2025

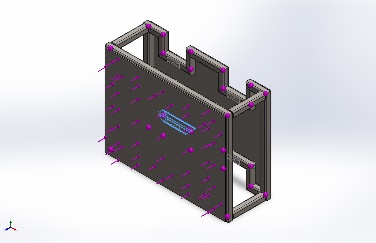
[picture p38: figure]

SolidBody 14(Trim/Extend10[1]) | Beam – Uniform C/S | Section Standard-weldment profiles/iso/square tube Section Area: 0.000133699m^2 Length:95mm Volume:1.27016e-05m^3 Mass Density:7,858kg/m^3 Mass:0.0998095kg Weight:0.978133N | C:\Users\USER\Desktop\Chassis Design\Box bar frame.SLDPRT Apr 1 23:41:29 2025
SolidBody 15(Trim/Extend21[2]) | Beam – Uniform C/S | Section Standard-weldment profiles/iso/square tube Section Area: 0.000133699m^2 Length:300mm Volume:4.01105e-05m^3 Mass Density:7,858kg/m^3 Mass:0.315188kg Weight:3.08884N | C:\Users\USER\Desktop\Chassis Design\Box bar frame.SLDPRT Apr 1 23:41:29 2025

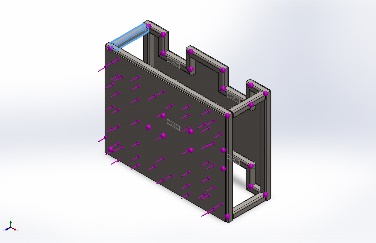
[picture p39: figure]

SolidBody 16(Square tube - configured 20 X 20 X 2(1)[25]) | Beam – Uniform C/S | Section Standard-weldment profiles/iso/square tube Section Area: 0.000133699m^2 Length:110mm Volume:1.47069e-05m^3 Mass Density:7,858kg/m^3 Mass:0.115567kg Weight:1.13256N | C:\Users\USER\Desktop\Chassis Design\Box bar frame.SLDPRT Apr 1 23:41:29 2025

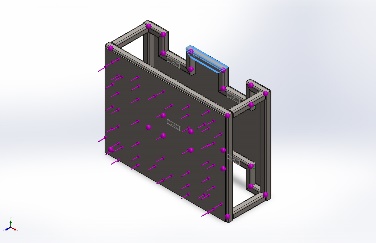
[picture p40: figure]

SolidBody 17(Trim/Extend3[2]) | Beam – Uniform C/S | Section Standard-weldment profiles/iso/square tube Section Area: 0.000133699m^2 Length:110mm Volume:1.47072e-05m^3 Mass Density:7,858kg/m^3 Mass:0.115569kg Weight:1.13258N | C:\Users\USER\Desktop\Chassis Design\Box bar frame.SLDPRT Apr 1 23:41:29 2025
SolidBody 18(Trim/Extend16[1]) | Beam – Uniform C/S | Section Standard-weldment profiles/iso/square tube Section Area: 0.000133699m^2 Length:300mm Volume:4.01105e-05m^3 Mass Density:7,858kg/m^3 Mass:0.315188kg Weight:3.08884N | C:\Users\USER\Desktop\Chassis Design\Box bar frame.SLDPRT Apr 1 23:41:29 2025

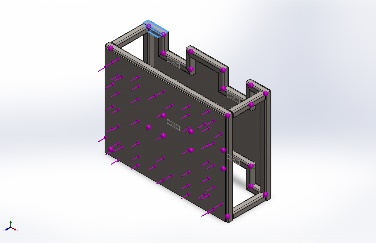
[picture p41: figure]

SolidBody 19(Trim/Extend7[1]) | Beam – Uniform C/S | Section Standard-weldment profiles/iso/square tube Section Area: 0.000133699m^2 Length:50mm Volume:6.68508e-06m^3 Mass Density:7,858kg/m^3 Mass:0.0525313kg Weight:0.514807N | C:\Users\USER\Desktop\Chassis Design\Box bar frame.SLDPRT Apr 1 23:41:29 2025
SolidBody 20(Trim/Extend21[1]) | Beam – Uniform C/S | Section Standard-weldment profiles/iso/square tube Section Area: 0.000133699m^2 Length:50mm Volume:6.68508e-06m^3 Mass Density:7,858kg/m^3 Mass:0.0525313kg Weight:0.514807N | C:\Users\USER\Desktop\Chassis Design\Box bar frame.SLDPRT Apr 1 23:41:29 2025

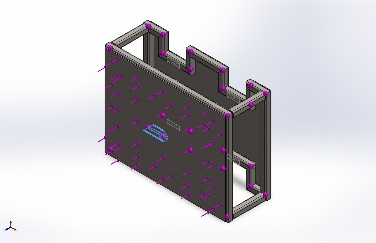
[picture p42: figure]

SolidBody 21(Trim/Extend24[2]) | Beam – Uniform C/S | Section Standard-weldment profiles/iso/square tube Section Area: 0.000133699m^2 Length:50mm Volume:6.68508e-06m^3 Mass Density:7,858kg/m^3 Mass:0.0525313kg Weight:0.514807N | C:\Users\USER\Desktop\Chassis Design\Box bar frame.SLDPRT Apr 1 23:41:29 2025

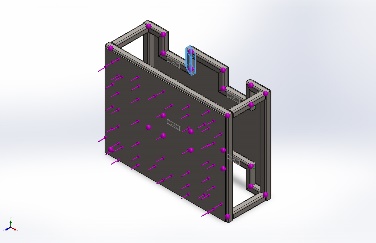
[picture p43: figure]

SolidBody 22(Trim/Extend4[1]) | Beam – Uniform C/S | Section Standard-weldment profiles/iso/square tube Section Area: 0.000133699m^2 Length:52.2184mm Volume:6.98168e-06m^3 Mass Density:7,858kg/m^3 Mass:0.054862kg Weight:0.537648N | C:\Users\USER\Desktop\Chassis Design\Box bar frame.SLDPRT Apr 1 23:41:29 2025
SolidBody 23(Trim/Extend2[2]) | Beam – Uniform C/S | Section Standard-weldment profiles/iso/square tube Section Area: 0.000133699m^2 Length:50mm Volume:6.68508e-06m^3 Mass Density:7,858kg/m^3 Mass:0.0525313kg Weight:0.514807N | C:\Users\USER\Desktop\Chassis Design\Box bar frame.SLDPRT Apr 1 23:41:29 2025

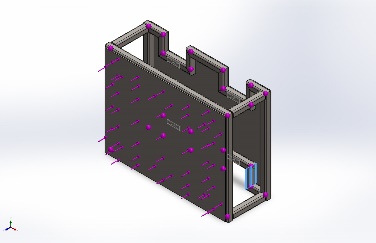
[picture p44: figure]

SolidBody 24(Trim/Extend11[2]) | Beam – Uniform C/S | Section Standard-weldment profiles/iso/square tube Section Area: 0.000133699m^2 Length:60.0036mm Volume:8.02257e-06m^3 Mass Density:7,858kg/m^3 Mass:0.0630413kg Weight:0.617805N | C:\Users\USER\Desktop\Chassis Design\Box bar frame.SLDPRT Apr 1 23:41:29 2025

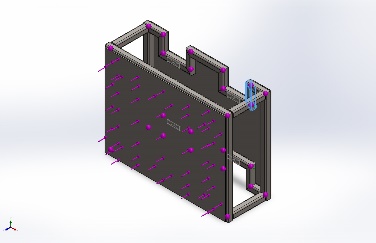
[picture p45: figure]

SolidBody 25(Trim/Extend22[2]) | Beam – Uniform C/S | Section Standard-weldment profiles/iso/square tube Section Area: 0.000133699m^2 Length:57.7816mm Volume:7.72549e-06m^3 Mass Density:7,858kg/m^3 Mass:0.0607069kg Weight:0.594927N | C:\Users\USER\Desktop\Chassis Design\Box bar frame.SLDPRT Apr 1 23:41:29 2025
SolidBody 26(Trim/Extend24[1]) | Beam – Uniform C/S | Section Standard-weldment profiles/iso/square tube Section Area: 0.000133699m^2 Length:300mm Volume:4.01105e-05m^3 Mass Density:7,858kg/m^3 Mass:0.315188kg Weight:3.08884N | C:\Users\USER\Desktop\Chassis Design\Box bar frame.SLDPRT Apr 1 23:41:29 2025

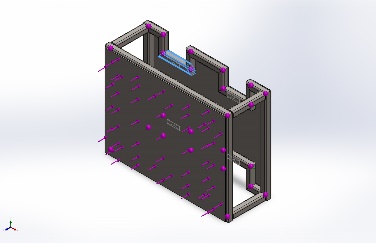
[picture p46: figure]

SolidBody 27(Trim/Extend5[2]) | Beam – Uniform C/S | Section Standard-weldment profiles/iso/square tube Section Area: 0.000133699m^2 Length:95mm Volume:1.27016e-05m^3 Mass Density:7,858kg/m^3 Mass:0.0998095kg Weight:0.978133N | C:\Users\USER\Desktop\Chassis Design\Box bar frame.SLDPRT Apr 1 23:41:29 2025
SolidBody 28(Square tube - configured 20 X 20 X 2(1)[27]) | Beam – Uniform C/S | Section Standard-weldment profiles/iso/square tube Section Area: 0.000133699m^2 Length:110mm Volume:1.47069e-05m^3 Mass Density:7,858kg/m^3 Mass:0.115567kg Weight:1.13256N | C:\Users\USER\Desktop\Chassis Design\Box bar frame.SLDPRT Apr 1 23:41:29 2025

# Study Properties

Study name | Chassis Weight Test
Analysis type | Static
Mesh type | Mixed Mesh
Thermal Effect: | On
Thermal option | Include temperature loads
Zero strain temperature | 298 Kelvin
Include fluid pressure effects from SOLIDWORKS Flow Simulation | Off
Solver type | Direct sparse solver
Inplane Effect: | Off
Soft Spring: | Off
Inertial Relief: | Off
Incompatible bonding options | Automatic
Large displacement | Off
Compute free body forces | On
Friction | Off
Use Adaptive Method: | Off
Result folder | SOLIDWORKS document (C:\Users\USER\Desktop\Chassis Design)

# Units

Unit system: | SI (MKS)
Length/Displacement | mm
Temperature | Kelvin
Angular velocity | Rad/sec
Pressure/Stress | N/m^2

# Material Properties

Model Reference | Properties | Components

Name: | 1023 Carbon Steel Sheet (SS)
Model type: | Linear Elastic Isotropic
Default failure criterion: | Max von Mises Stress
Yield strength: | 2.82685e+08 N/m^2
Tensile strength: | 4.25e+08 N/m^2
Elastic modulus: | 2.05e+11 N/m^2
Poisson's ratio: | 0.29
Mass density: | 7,858 kg/m^3
Shear modulus: | 8e+10 N/m^2
Thermal expansion coefficient: | 1.2e-05 /Kelvin

SolidBody 1(Boss-Extrude1)(Bottom Plate-1),

SolidBody 1(Trim/Extend14[2])(Box bar frame-1),

SolidBody 2(Trim/Extend19[2])(Box bar frame-1),

SolidBody 3(Trim/Extend5[1])(Box bar frame-1),

SolidBody 4(Trim/Extend22[1])(Box bar frame-1),

SolidBody 5(Trim/Extend20[2])(Box bar frame-1),

SolidBody 6(Square tube - configured 20 X 20 X 2(1)[24])(Box bar frame-1),

SolidBody 7(Trim/Extend23[2])(Box bar frame-1),

SolidBody 8(Trim/Extend14[1])(Box bar frame-1),

SolidBody 9(Trim/Extend8[1])(Box bar frame-1),

SolidBody 10(Trim/Extend20[1])(Box bar frame-1),

SolidBody 11(Square tube - configured 20 X 20 X 2(1)[26])(Box bar frame-1),

SolidBody 12(Trim/Extend18[1])(Box bar frame-1),

SolidBody 13(Trim/Extend16[2])(Box bar frame-1),

SolidBody 14(Trim/Extend10[1])(Box bar frame-1),

SolidBody 15(Trim/Extend21[2])(Box bar frame-1),

SolidBody 16(Square tube - configured 20 X 20 X 2(1)[25])(Box bar frame-1),

SolidBody 17(Trim/Extend3[2])(Box bar frame-1),

SolidBody 18(Trim/Extend16[1])(Box bar frame-1),

SolidBody 19(Trim/Extend7[1])(Box bar frame-1),

SolidBody 20(Trim/Extend21[1])(Box bar frame-1),

SolidBody 21(Trim/Extend24[2])(Box bar frame-1),

SolidBody 22(Trim/Extend4[1])(Box bar frame-1),

SolidBody 23(Trim/Extend2[2])(Box bar frame-1),

SolidBody 24(Trim/Extend11[2])(Box bar frame-1),

SolidBody 25(Trim/Extend22[2])(Box bar frame-1),

SolidBody 26(Trim/Extend24[1])(Box bar frame-1),

SolidBody 27(Trim/Extend5[2])(Box bar frame-1),

SolidBody 28(Square tube - configured 20 X 20 X 2(1)[27])(Box bar frame-1),

SolidBody 1(Boss-Extrude1)(Top Plate-1)

Curve Data:N/A

# Loads and Fixtures

Fixture name | Fixture Image | Fixture Details
Fixed-1 | | Type: Fixed Geometry

Load name | Load Image | Load Details
Force-1 | | Entities: 1 face(s) Type: Apply normal force Value: 98.1 N

# Connector Definitions

No Data

# Interaction Information

Interaction | Interaction Image | Interaction Properties
Component Contact-2 | | Type: Bonded Components: 3 component(s) Options: Continuous mesh

# Mesh information

Mesh type | Mixed Mesh
Mesher Used: | Standard mesh
Automatic Transition: | Off
Include Mesh Auto Loops: | Off
Jacobian points for High quality mesh | 16 Points
Jacobian check for shell | On
Element Size | 8.69331 mm
Tolerance | 0.434666 mm
Mesh Quality | High
Remesh failed parts independently | Off

## Mesh information - Details

Total Nodes | 41488
Total Elements | 20734
Time to complete mesh(hh;mm;ss): | 00:00:07
Computer name:

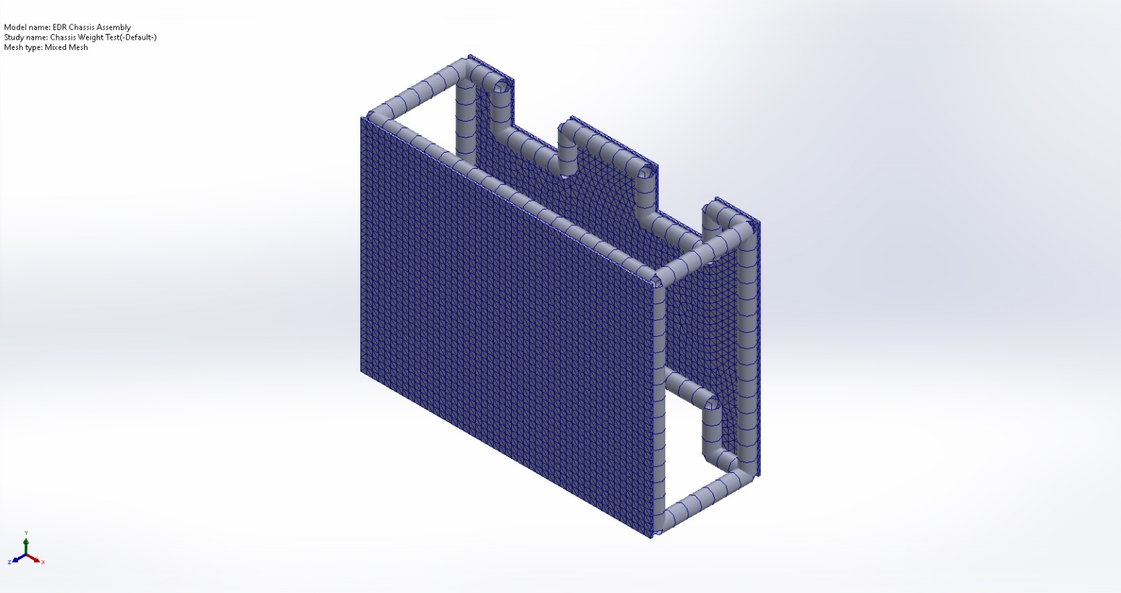
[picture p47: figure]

# Sensor Details

No Data

# Resultant Forces

## Reaction forces

Selection set | Units | Sum X | Sum Y | Sum Z | Resultant
Entire Model | N | -9.53674e-07 | 0 | 98.1 | 98.1

## Reaction Moments

Selection set | Units | Sum X | Sum Y | Sum Z | Resultant
Entire Model | N.m | -0.158036 | 0.00327212 | 0.00951537 | 0.158356

## Free body forces

Selection set | Units | Sum X | Sum Y | Sum Z | Resultant
Entire Model | N | 4.34408e-05 | 6.35556e-06 | 0.00370944 | 0.0037097

## Free body moments

Selection set | Units | Sum X | Sum Y | Sum Z | Resultant
Entire Model | N.m | 0 | 0 | 0 | 1e-33

# Beams

## Beam Forces

Beam Name | Joints | Axial(N) | Shear1(N) | Shear2(N) | Moment1(N.m) | Moment2(N.m) | Torque(N.m)
Beam-1(Trim/Extend14[2]) | 1 | -1.84929 | 10.1222 | 14.2267 | 0.478417 | -0.277077 | 0.385963
| 2 | 1.42657 | 10.258 | 14.3817 | -0.472211 | 0.278891 | 0.373873
Beam-2(Trim/Extend19[2]) | 1 | -4.15636 | 7.91991 | 24.5527 | -1.24867 | 0.287536 | -0.535613
| 2 | 4.15634 | -7.91992 | -24.5527 | -0.224579 | 0.187687 | 0.535614
Beam-3(Trim/Extend5[1]) | 1 | -4.3206 | -8.77183 | -24.4864 | 0.201346 | -0.193106 | 0.560348
| 2 | 4.32061 | 8.77183 | 24.4864 | 1.14541 | -0.289344 | -0.560347
Beam-4(Trim/Extend22[1]) | 1 | 0 | 0 | 0 | 0 | 0 | 0
| 2 | 0 | 0 | 0 | 0 | 0 | 0
Beam-5(Trim/Extend20[2]) | 1 | 0 | 0 | 0 | 0 | 0 | 0
| 2 | 0 | 0 | 0 | 0 | 0 | 0
Beam-6(Square tube - configured 20 X 20 X 2(1)[24]) | 1 | -24.4932 | -4.33938 | 1.72135 | 0.812377 | 0.577941 | -0.0149599
| 2 | 24.4932 | 4.33938 | -1.72139 | -0.588599 | -0.0138222 | 0.0149594
Beam-7(Trim/Extend23[2]) | 1 | 0 | 0 | 0 | 0 | 0 | 0
| 2 | 0 | 0 | 0 | 0 | 0 | 0
Beam-8(Trim/Extend14[1]) | 1 | 4.9811 | -6.66492 | 9.41163 | 0.185514 | 0.250007 | -0.250512
| 2 | -5.24788 | -6.8651 | 9.48519 | -0.186103 | -0.255305 | -0.259368
Beam-9(Trim/Extend8[1]) | 1 | 0 | 0 | 0 | 0 | 0 | 0
| 2 | 0 | 0 | 0 | 0 | 0 | 0
Beam-10(Trim/Extend20[1]) | 1 | 0 | 0 | 0 | 0 | 0 | 0
| 2 | 0 | 0 | 0 | 0 | 0 | 0
Beam-11(Square tube - configured 20 X 20 X 2(1)[26]) | 1 | -24.5173 | 4.39459 | -1.46506 | -0.79919 | -0.58404 | -0.0142112
| 2 | 24.5173 | -4.39459 | 1.46514 | 0.608728 | 0.012744 | 0.0142103
Beam-12(Trim/Extend18[1]) | 1 | 0 | 0 | 0 | 0 | 0 | 0
| 2 | 0 | 0 | 0 | 0 | 0 | 0
Beam-13(Trim/Extend16[2]) | 1 | -1.38725 | -10.4253 | 14.416 | 0.475579 | 0.284548 | -0.371876
| 2 | 1.74903 | -10.2737 | 14.1306 | -0.477107 | -0.282131 | -0.384937
Beam-14(Trim/Extend10[1]) | 1 | 0 | 0 | 0 | 0 | 0 | 0
| 2 | 0 | 0 | 0 | 0 | 0 | 0
Beam-15(Trim/Extend21[2]) | 1 | -6.24518 | -1.41177 | 0.229724 | -0.135999 | -0.0103495 | -0.0250711
| 2 | 6.25357 | -1.07015 | 0.843512 | 0.149318 | -0.000939775 | -0.0250649
Beam-16(Square tube - configured 20 X 20 X 2(1)[25]) | 1 | -24.5222 | -4.51047 | -1.86341 | -0.819683 | 0.58631 | 0.016867
| 2 | 24.5221 | 4.51047 | 1.86349 | 0.577435 | 5.02686e-05 | -0.0168661
Beam-17(Trim/Extend3[2]) | 1 | 0 | 0 | 0 | 0 | 0 | 0
| 2 | 0 | 0 | 0 | 0 | 0 | 0
Beam-18(Trim/Extend16[1]) | 1 | 5.20263 | 6.77137 | 9.21015 | 0.190038 | -0.25309 | 0.248757
| 2 | -5.77782 | 6.93871 | 9.66934 | -0.192638 | 0.257112 | 0.257203
Beam-19(Trim/Extend7[1]) | 1 | 8.77183 | -4.3206 | 24.4864 | 0.560348 | 0.193106 | -0.201346
| 2 | -8.77183 | 4.3206 | -24.4864 | 0.66397 | 0.0229238 | 0.201346
Beam-20(Trim/Extend21[1]) | 1 | 8.10866 | -4.4337 | -24.6019 | -0.686886 | 0.0251607 | -0.227599
| 2 | -8.10866 | 4.4337 | 24.6019 | -0.543208 | 0.196524 | 0.227599
Beam-21(Trim/Extend24[2]) | 1 | 7.91991 | 4.15635 | 24.5527 | 0.535614 | -0.187687 | 0.224579
| 2 | -7.91991 | -4.15635 | -24.5527 | 0.692022 | -0.0201308 | -0.224579
Beam-22(Trim/Extend4[1]) | 1 | 0 | 0 | 0 | 0 | 0 | 0
| 2 | 0 | 0 | 0 | 0 | 0 | 0
Beam-23(Trim/Extend2[2]) | 1 | 8.58309 | 4.26944 | -24.459 | -0.673469 | -0.0188751 | 0.219448
| 2 | -8.58309 | -4.26944 | 24.459 | -0.549482 | -0.194597 | -0.219448
Beam-24(Trim/Extend11[2]) | 1 | -4.4337 | -8.10865 | 24.6019 | -1.2486 | -0.290024 | 0.543208
| 2 | 4.43369 | 8.10866 | -24.6019 | -0.2276 | -0.196524 | -0.543208
Beam-25(Trim/Extend22[2]) | 1 | 4.26945 | -8.58309 | 24.459 | 1.19383 | 0.301348 | 0.549481
| 2 | -4.26944 | 8.58309 | -24.459 | 0.219448 | 0.194597 | -0.549482
Beam-26(Trim/Extend24[1]) | 1 | 6.33621 | 1.26465 | 0.25256 | 0.14274 | -0.007208 | 0.0260117
| 2 | -6.21188 | 1.25204 | 0.478026 | -0.135821 | 0.0024686 | 0.0222519
Beam-27(Trim/Extend5[2]) | 1 | 0 | 0 | 0 | 0 | 0 | 0
| 2 | 0 | 0 | 0 | 0 | 0 | 0
Beam-28(Square tube - configured 20 X 20 X 2(1)[27]) | 1 | -24.5674 | 4.45523 | 1.60716 | 0.810734 | -0.590589 | 0.0160187
| 2 | 24.5674 | -4.45523 | -1.6072 | -0.601801 | 0.0114093 | -0.0160182

## Beam Stresses

Beam Name | Joints | Axial(N/m^2) | Bending Dir1(N/m^2) | Bending Dir2(N/m^2) | Torsional (N/m^2) | Upper bound axial and bending(N/m^2)
Beam-1(Trim/Extend14[2]) | 1 | -13,831.7 | 691,188 | 400,304 | 397,778 | 1.10532e+06
| 2 | -10,670 | 682,222 | 402,925 | 385,318 | 1.09582e+06
Beam-2(Trim/Extend19[2]) | 1 | 31,087.4 | 1.80401e+06 | 415,415 | -552,010 | 2.25051e+06
| 2 | 31,087.3 | -324,458 | -271,158 | 552,011 | 626,704
Beam-3(Trim/Extend5[1]) | 1 | 32,315.8 | -290,893 | -278,988 | 577,502 | 602,197
| 2 | 32,315.9 | 1.65481e+06 | 418,027 | -577,501 | 2.10515e+06
Beam-4(Trim/Extend22[1]) | 1 | 0 | 0 | 0 | 0 | 0
| 2 | 0 | 0 | 0 | 0 | 0
Beam-5(Trim/Extend20[2]) | 1 | 0 | 0 | 0 | 0 | 0
| 2 | 0 | 0 | 0 | 0 | 0
Beam-6(Square tube - configured 20 X 20 X 2(1)[24]) | 1 | -183,197 | 1.17367e+06 | -834,975 | -15,417.8 | 2.19184e+06
| 2 | -183,197 | 850,372 | -19,969.5 | 15,417.3 | 1.05354e+06
Beam-7(Trim/Extend23[2]) | 1 | 0 | 0 | 0 | 0 | 0
| 2 | 0 | 0 | 0 | 0 | 0
Beam-8(Trim/Extend14[1]) | 1 | 37,256.1 | 268,019 | -361,195 | -258,181 | 666,470
| 2 | 39,251.4 | 268,870 | -368,850 | -267,308 | 676,971
Beam-9(Trim/Extend8[1]) | 1 | 0 | 0 | 0 | 0 | 0
| 2 | 0 | 0 | 0 | 0 | 0
Beam-10(Trim/Extend20[1]) | 1 | 0 | 0 | 0 | 0 | 0
| 2 | 0 | 0 | 0 | 0 | 0
Beam-11(Square tube - configured 20 X 20 X 2(1)[26]) | 1 | -183,376 | -1.15462e+06 | 843,786 | -14,646.3 | 2.18178e+06
| 2 | -183,376 | -879,453 | 18,411.8 | 14,645.3 | 1.08124e+06
Beam-12(Trim/Extend18[1]) | 1 | 0 | 0 | 0 | 0 | 0
| 2 | 0 | 0 | 0 | 0 | 0
Beam-13(Trim/Extend16[2]) | 1 | -10,375.9 | 687,087 | -411,098 | -383,260 | 1.10856e+06
| 2 | -13,081.8 | 689,295 | -407,606 | -396,721 | 1.10998e+06
Beam-14(Trim/Extend10[1]) | 1 | 0 | 0 | 0 | 0 | 0
| 2 | 0 | 0 | 0 | 0 | 0
Beam-15(Trim/Extend21[2]) | 1 | 46,710.7 | 196,484 | -14,952.3 | -25,838.6 | 258,147
| 2 | 46,773.5 | 215,726 | 1,357.73 | -25,832.2 | 263,857
Beam-16(Square tube - configured 20 X 20 X 2(1)[25]) | 1 | -183,413 | -1.18423e+06 | -847,066 | 17,383.4 | 2.21471e+06
| 2 | -183,413 | -834,243 | 72.625 | -17,382.4 | 1.01773e+06
Beam-17(Trim/Extend3[2]) | 1 | 0 | 0 | 0 | 0 | 0
| 2 | 0 | 0 | 0 | 0 | 0
Beam-18(Trim/Extend16[1]) | 1 | 38,912.9 | 274,556 | 365,650 | 256,372 | 679,118
| 2 | 43,215.1 | 278,312 | 371,460 | 265,077 | 692,987
Beam-19(Trim/Extend7[1]) | 1 | 65,608.7 | 809,557 | -278,988 | -207,510 | 1.15415e+06
| 2 | 65,608.7 | -959,264 | 33,118.9 | 207,510 | 1.05799e+06
Beam-20(Trim/Extend21[1]) | 1 | 60,648.5 | -992,371 | -36,350.6 | -234,567 | 1.08937e+06
| 2 | 60,648.5 | 784,795 | 283,926 | 234,567 | 1.12937e+06
Beam-21(Trim/Extend24[2]) | 1 | 59,236.9 | 773,823 | 271,158 | 231,453 | 1.10422e+06
| 2 | 59,236.9 | -999,791 | -29,083.7 | -231,453 | 1.08811e+06
Beam-22(Trim/Extend4[1]) | 1 | 0 | 0 | 0 | 0 | 0
| 2 | 0 | 0 | 0 | 0 | 0
Beam-23(Trim/Extend2[2]) | 1 | 64,197.1 | -972,987 | 27,269.6 | 226,166 | 1.06445e+06
| 2 | 64,197.1 | 793,858 | -281,142 | -226,166 | 1.1392e+06
Beam-24(Trim/Extend11[2]) | 1 | 33,161.8 | 1.8039e+06 | -419,009 | 559,837 | 2.25608e+06
| 2 | 33,161.7 | -328,822 | 283,926 | -559,837 | 645,910
Beam-25(Trim/Extend22[2]) | 1 | 31,933.2 | 1.72478e+06 | -435,369 | 566,302 | 2.19208e+06
| 2 | 31,933.2 | -317,046 | 281,142 | -566,303 | 630,121
Beam-26(Trim/Extend24[1]) | 1 | 47,391.6 | 206,221 | 10,413.7 | 26,808 | 264,027
| 2 | 46,461.7 | 196,226 | 3,566.48 | 22,933.1 | 246,254
Beam-27(Trim/Extend5[2]) | 1 | 0 | 0 | 0 | 0 | 0
| 2 | 0 | 0 | 0 | 0 | 0
Beam-28(Square tube - configured 20 X 20 X 2(1)[27]) | 1 | -183,751 | 1.1713e+06 | 853,247 | 16,509.1 | 2.2083e+06
| 2 | -183,751 | 869,445 | 16,483.5 | -16,508.6 | 1.06968e+06

# Study Results

Name | Type | Min | Max
Stress1 | SX: X Normal Stress | -1.571e+06N/m^2 Element: 10696 | 1.499e+06N/m^2 Element: 17976

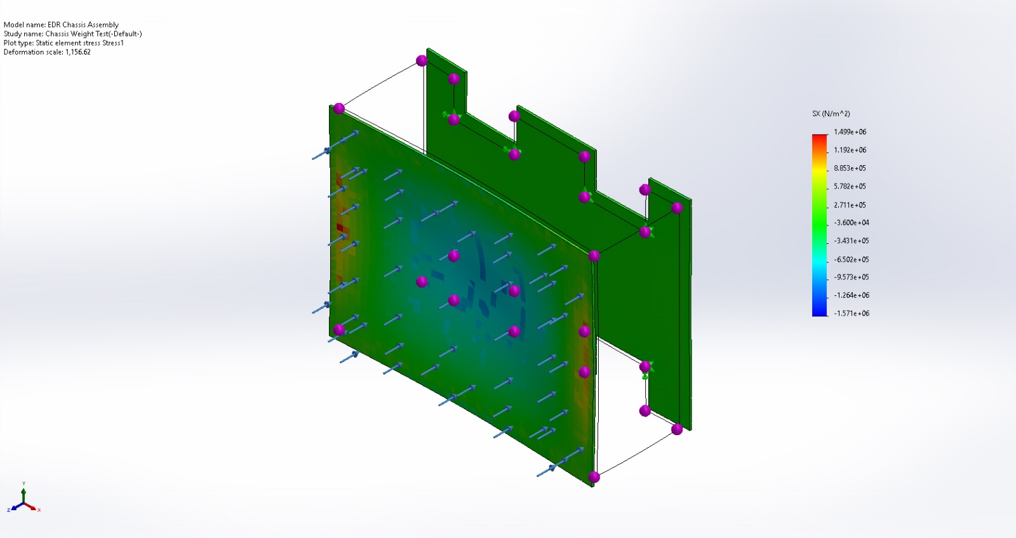
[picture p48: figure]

EDR Chassis Assembly-Chassis Weight Test-Stress-Stress1

Name | Type | Min | Max
Displacement1 | URES: Resultant Displacement | 0.000e+00mm Node: 41290 | 3.747e-02mm Node: 39397

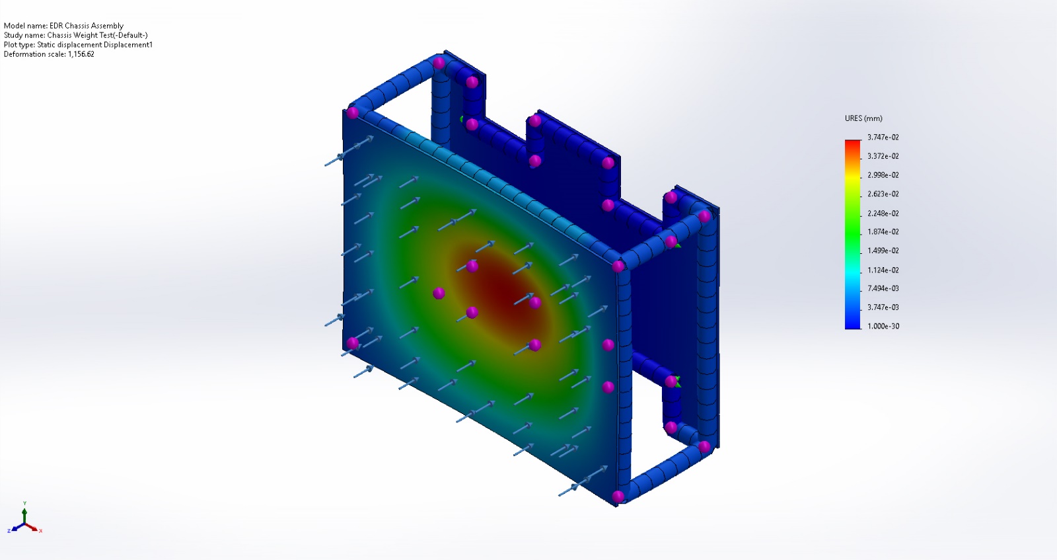
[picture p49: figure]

EDR Chassis Assembly-Chassis Weight Test-Displacement-Displacement1

Name | Type | Min | Max
Strain1 | ESTRN: Equivalent Strain | 0.000e+00 Element: 20539 | 7.174e-06 Element: 16349

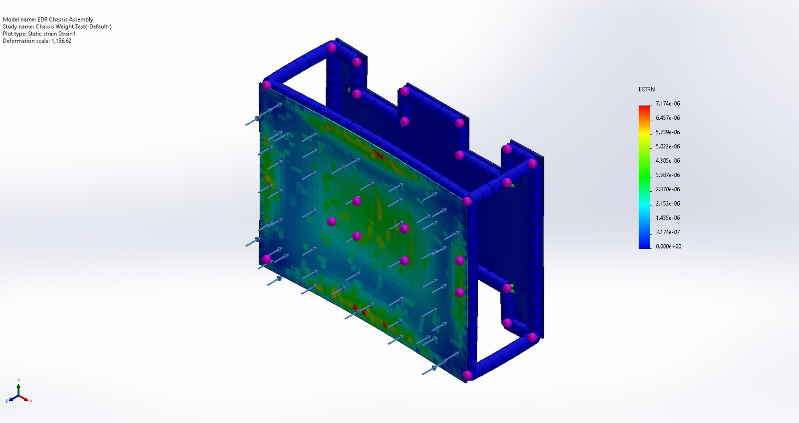
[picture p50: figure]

EDR Chassis Assembly-Chassis Weight Test-Strain-Strain1

Image-1

Image-2

Image-3

Image-4

Image-5

Image-6

Image-7

Image-8

Image-9

Image-10

# Conclusion

Analyzed with SOLIDWORKS Simulation Simulation of EDR Chassis Assembly 16

Analyzed with SOLIDWORKS Simulation Simulation of EDR Chassis Assembly 1

Omni-Directional Robot Omni-Directional Robot 4/2/2025

Omni-Directional Robot

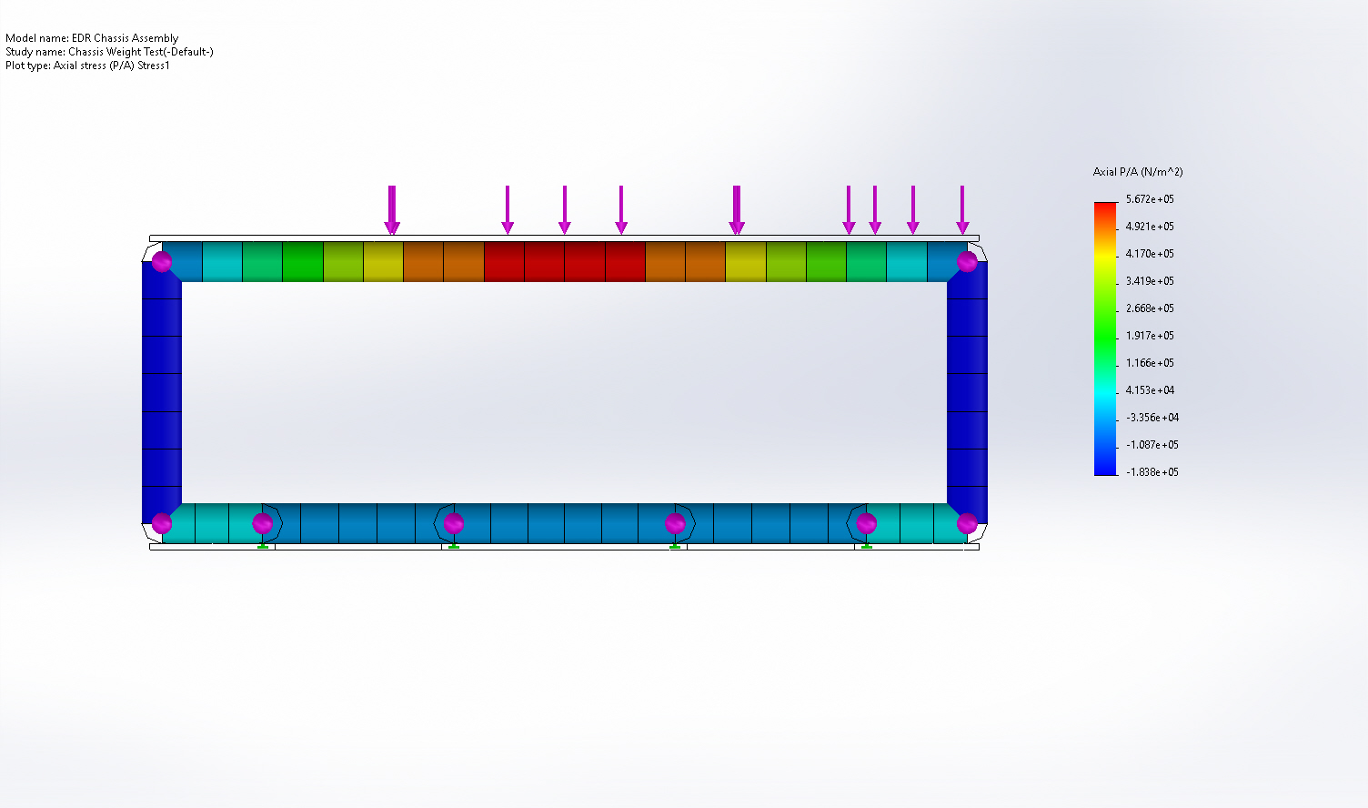
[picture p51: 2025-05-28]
Mechanical Designs/Finite Element Analysis/EDR Chassis Assembly-Chassis Weight Test-Image-1.jpg

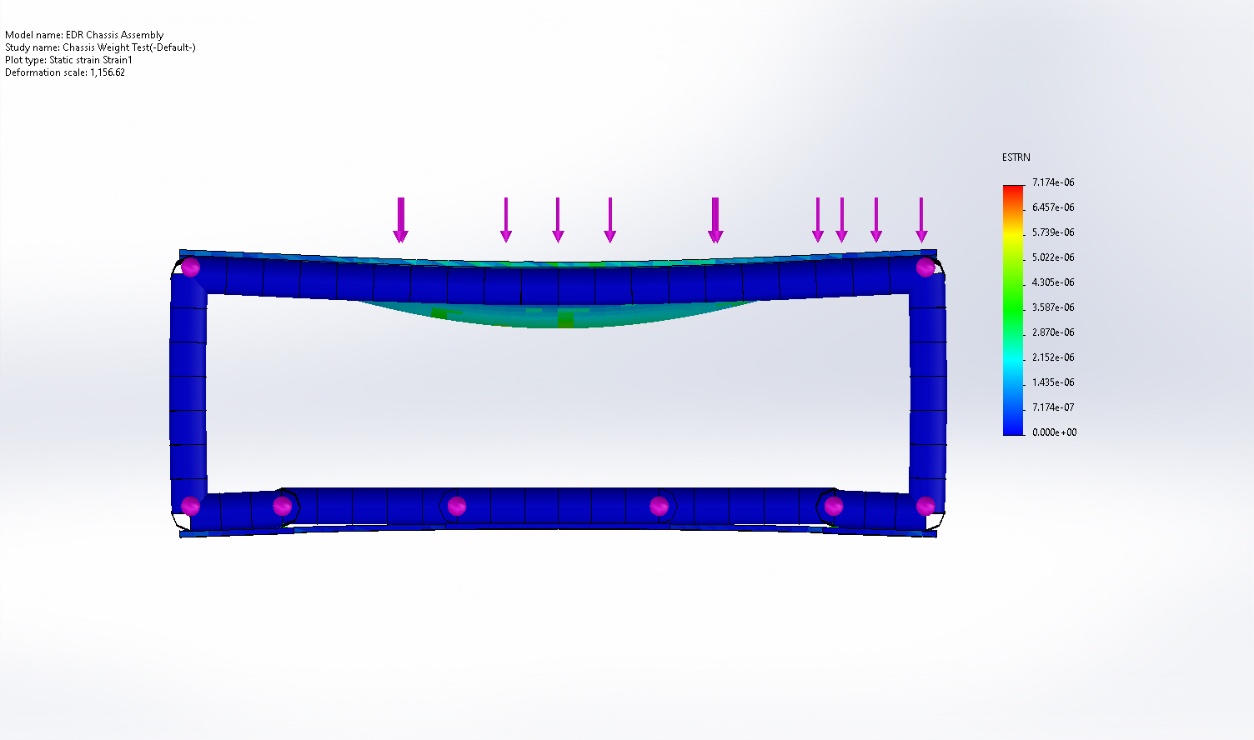
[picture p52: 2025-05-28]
Mechanical Designs/Finite Element Analysis/EDR Chassis Assembly-Chassis Weight Test-Image-10.jpg

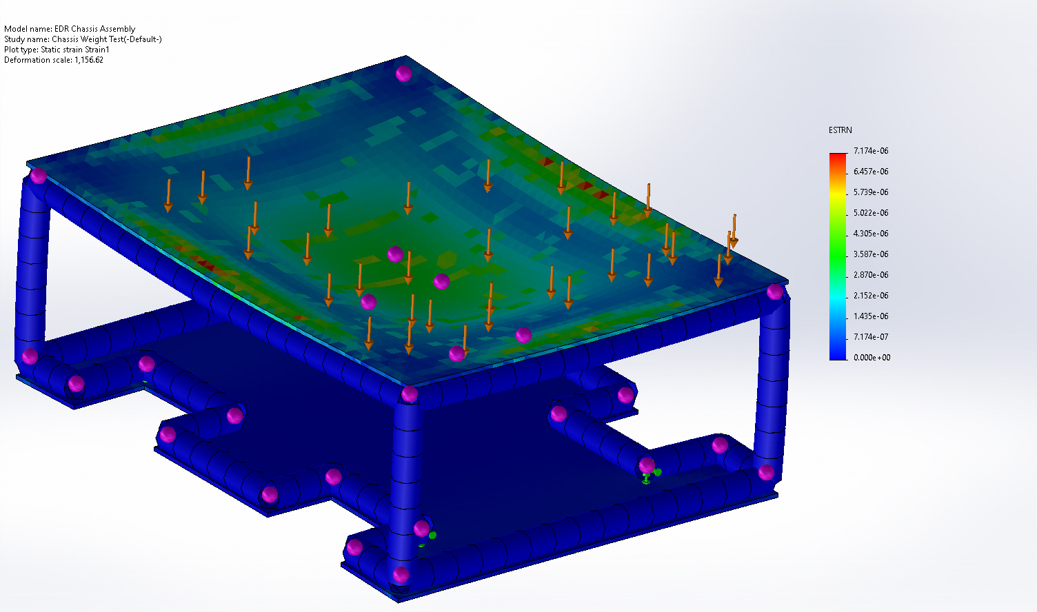
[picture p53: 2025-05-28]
Mechanical Designs/Finite Element Analysis/EDR Chassis Assembly-Chassis Weight Test-Image-9.jpg

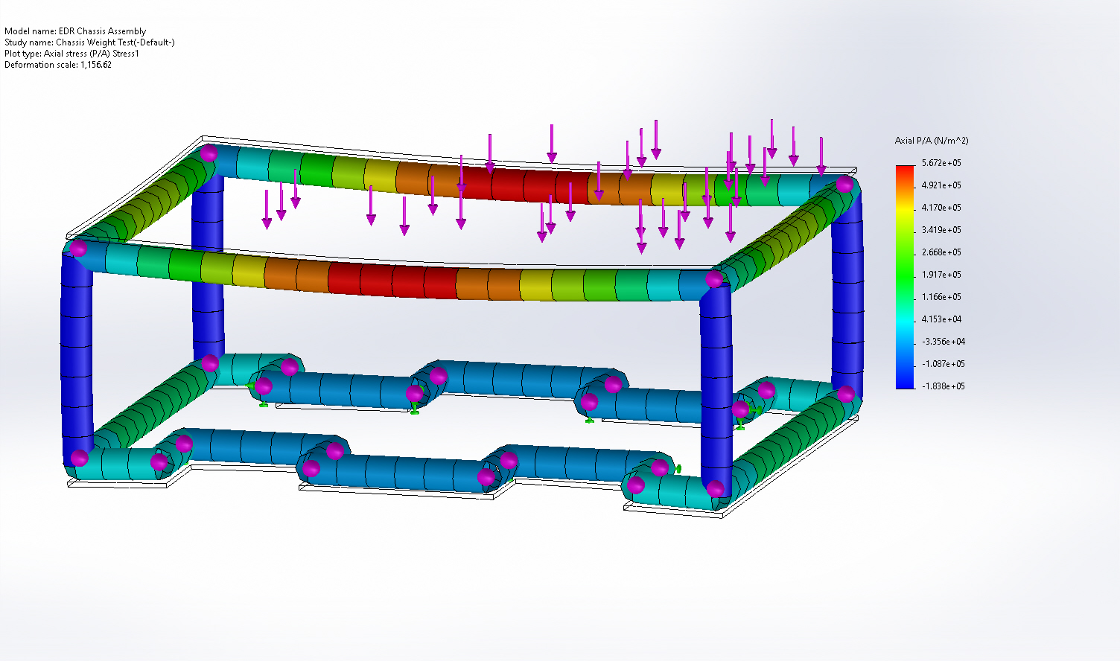
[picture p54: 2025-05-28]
Mechanical Designs/Finite Element Analysis/EDR Chassis Assembly-Chassis Weight Test-Image-3.jpg

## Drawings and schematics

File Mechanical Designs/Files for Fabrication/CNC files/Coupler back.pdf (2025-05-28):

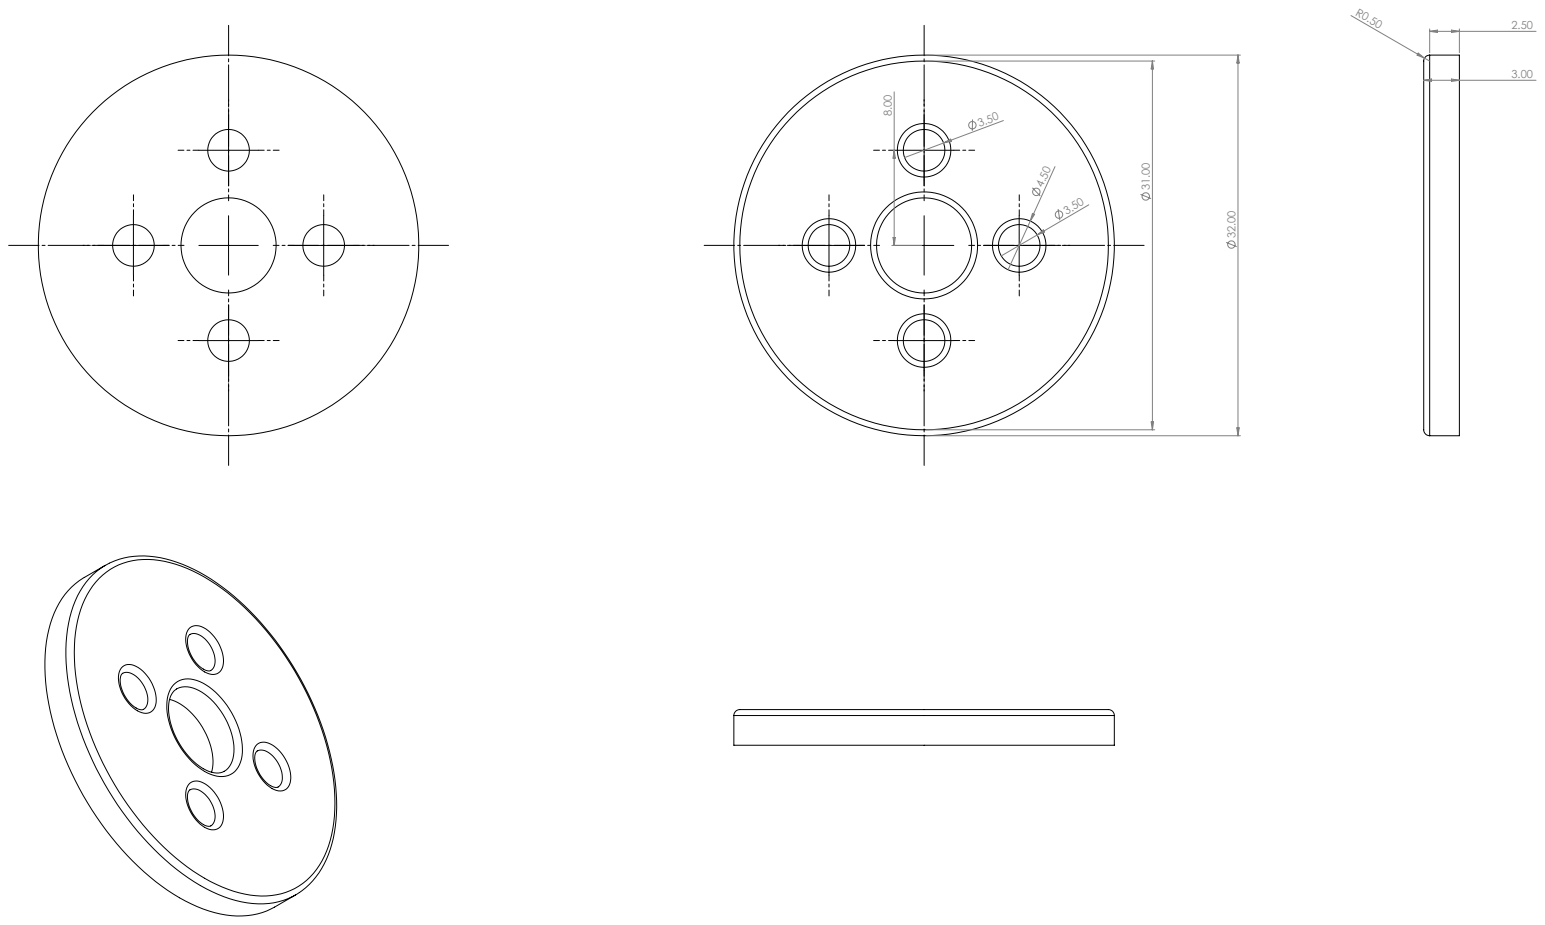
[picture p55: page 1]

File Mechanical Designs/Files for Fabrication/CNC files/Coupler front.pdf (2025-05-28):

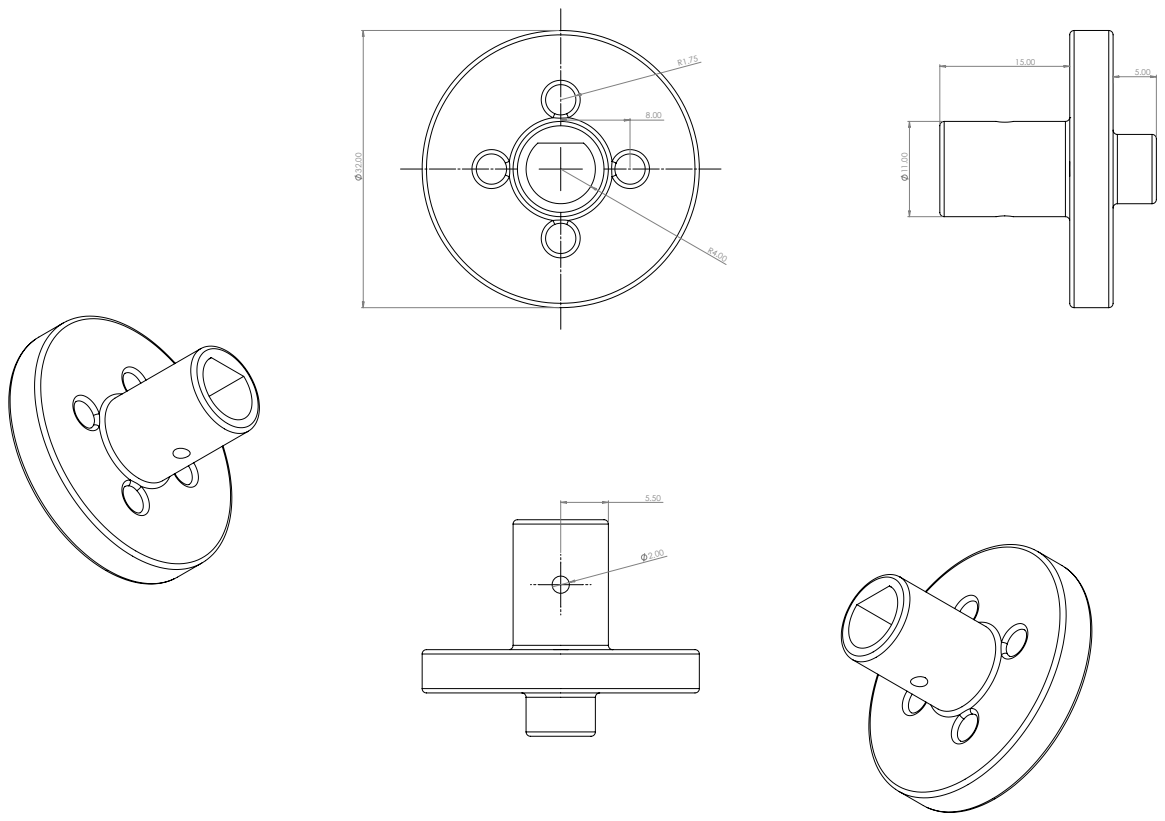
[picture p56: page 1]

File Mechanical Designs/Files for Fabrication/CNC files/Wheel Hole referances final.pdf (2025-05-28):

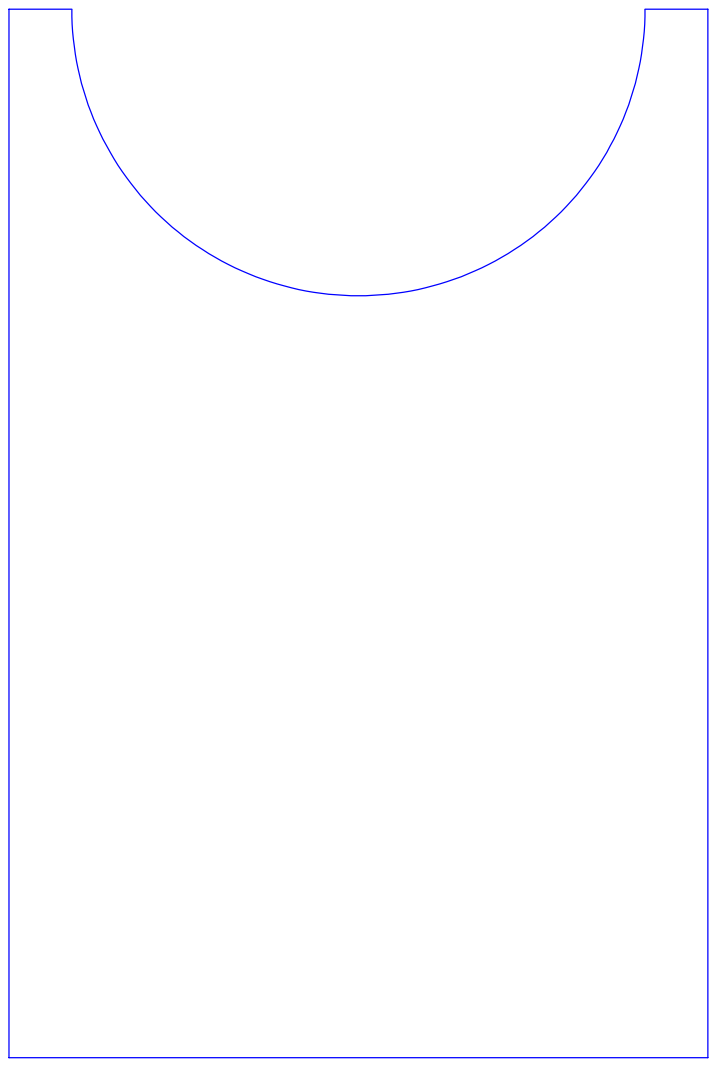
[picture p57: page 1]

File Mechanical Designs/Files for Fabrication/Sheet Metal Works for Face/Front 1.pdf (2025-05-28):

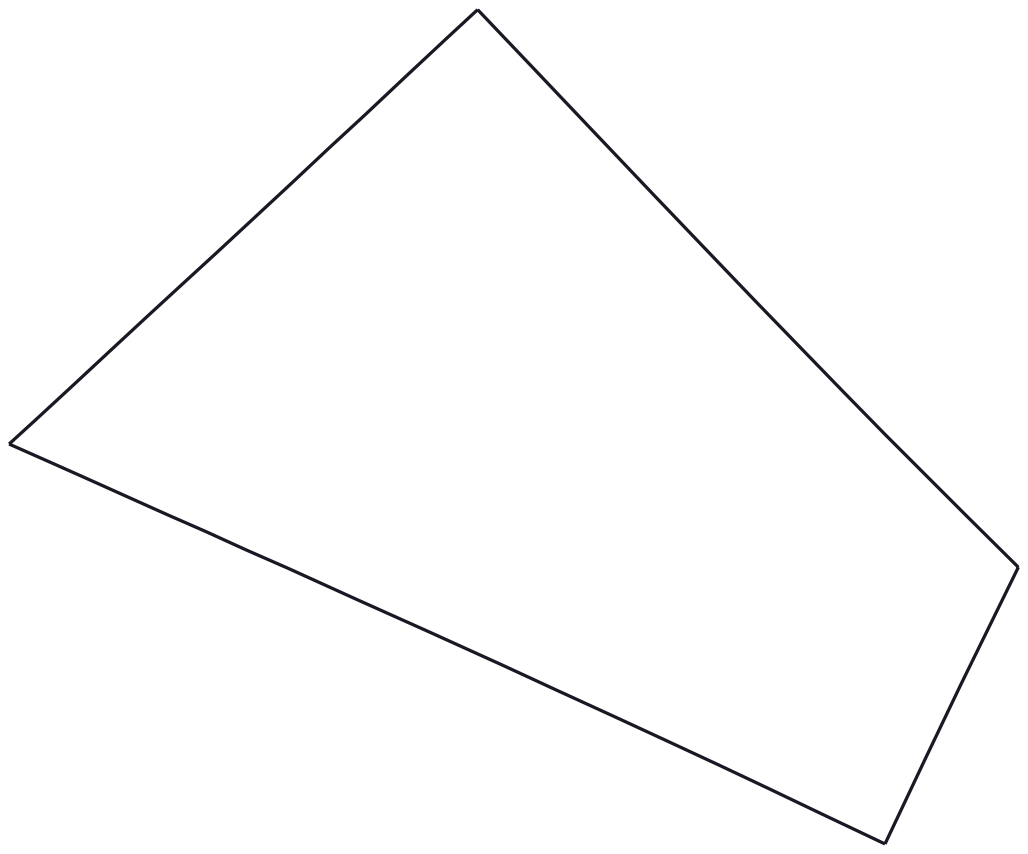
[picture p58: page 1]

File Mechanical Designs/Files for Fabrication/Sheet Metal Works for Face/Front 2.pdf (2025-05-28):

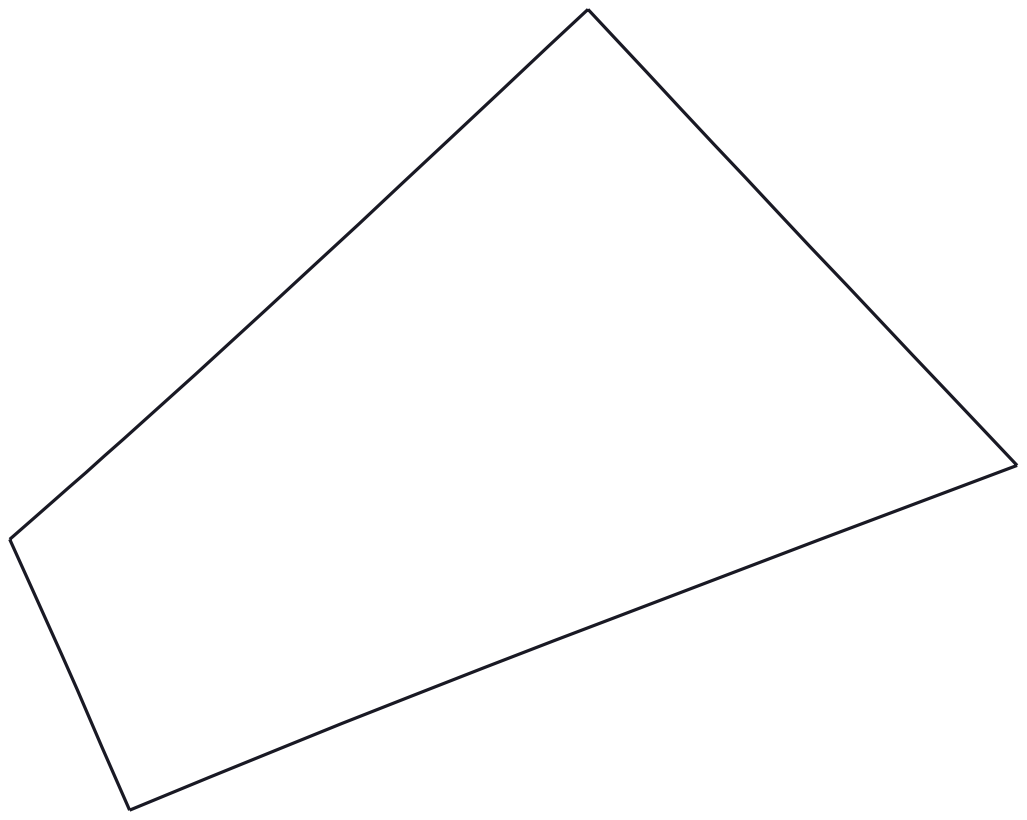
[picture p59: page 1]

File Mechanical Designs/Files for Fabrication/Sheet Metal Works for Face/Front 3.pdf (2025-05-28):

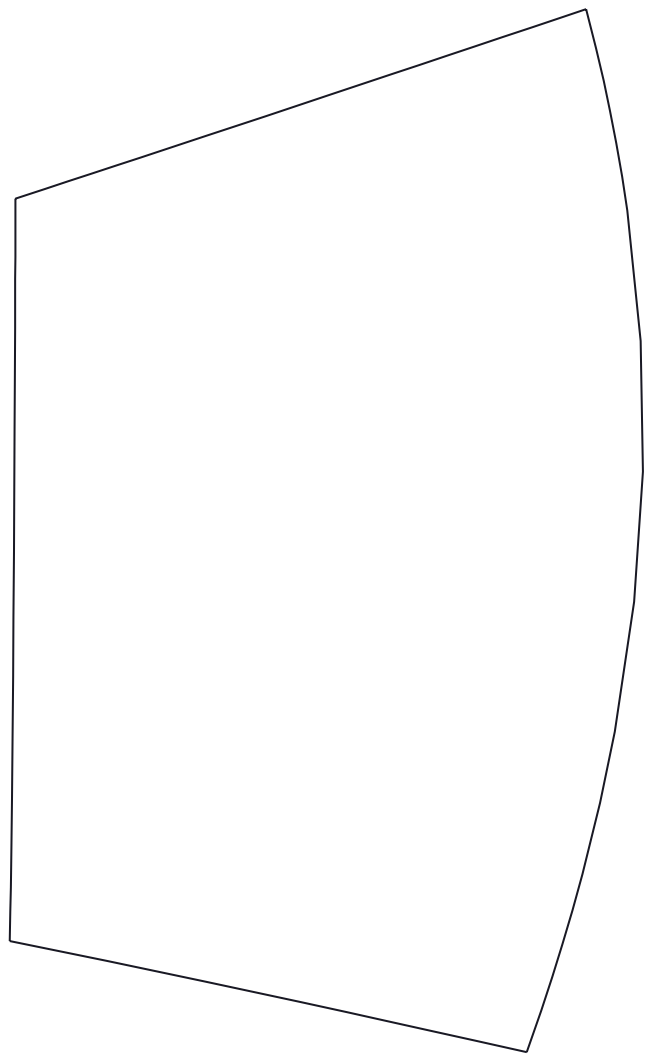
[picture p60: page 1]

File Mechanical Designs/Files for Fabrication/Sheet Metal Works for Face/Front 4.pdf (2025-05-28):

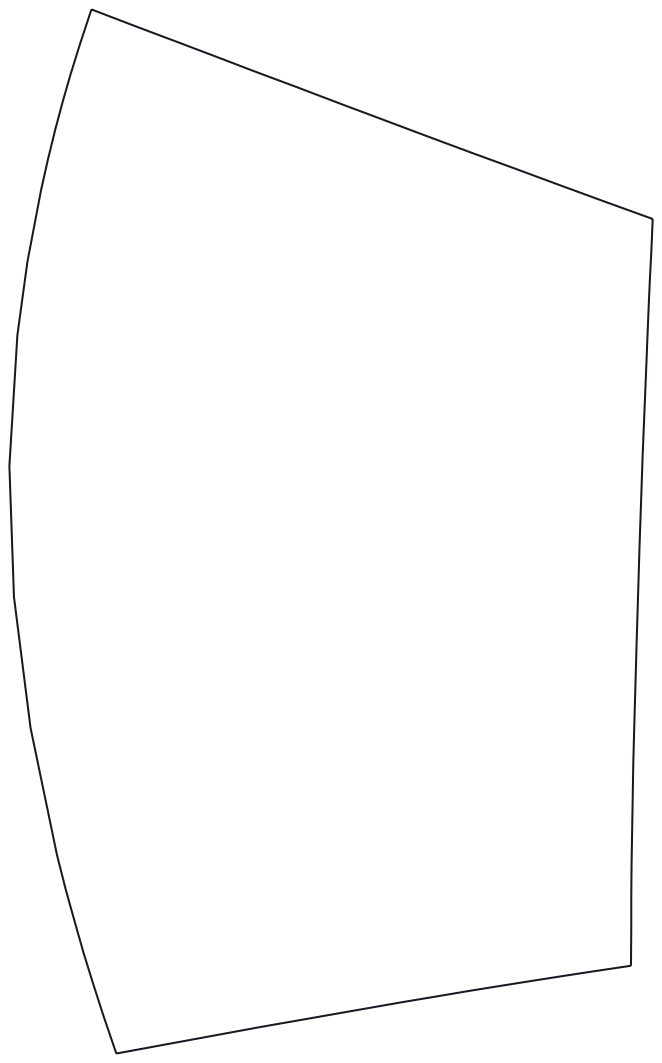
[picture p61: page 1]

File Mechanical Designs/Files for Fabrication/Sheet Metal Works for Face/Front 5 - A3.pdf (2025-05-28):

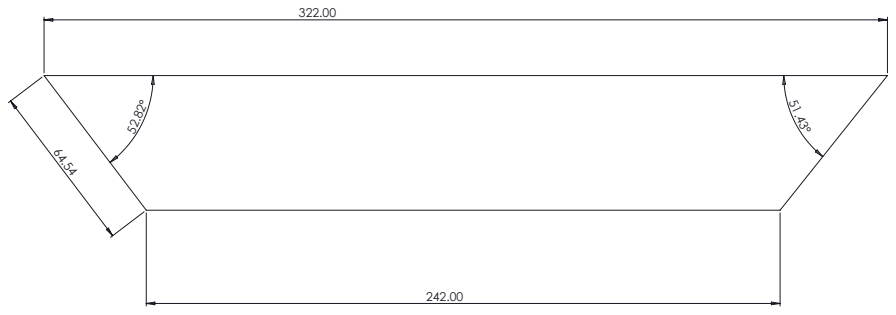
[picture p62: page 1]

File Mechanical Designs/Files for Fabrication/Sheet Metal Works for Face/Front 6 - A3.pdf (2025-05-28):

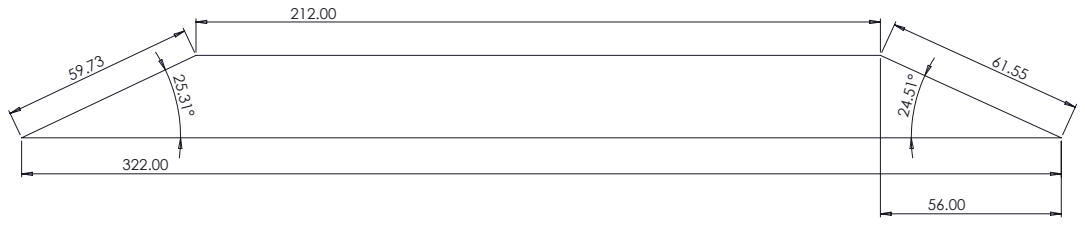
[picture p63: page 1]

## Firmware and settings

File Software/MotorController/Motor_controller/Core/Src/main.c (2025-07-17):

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
/* Includes ------------------------------------------------------------------*/
#include "main.h"

/* USER CODE BEGIN Includes */
#include "motors.h"
#include "encoders.h"
#include "kinematics.h"
#include "bluetoothDebug.h"
#include "delay.h"
#include "profile.h"
#include "controller.h"
#include "motion.h"
#include "RS485.h"

/* USER CODE END Includes */

ADC_HandleTypeDef hadc1;
DMA_HandleTypeDef hdma_adc1;

TIM_HandleTypeDef htim1;
TIM_HandleTypeDef htim2;
TIM_HandleTypeDef htim3;
TIM_HandleTypeDef htim4;
TIM_HandleTypeDef htim5;
TIM_HandleTypeDef htim11;
TIM_HandleTypeDef htim13;
TIM_HandleTypeDef htim14;

UART_HandleTypeDef huart2;
UART_HandleTypeDef huart3;

/* USER CODE BEGIN PV */
uint32_t adc_values[4];
uint8_t rx_idx;
uint8_t rx_buff[100];
uint8_t rx_data[2];

extern float x_distance;
extern float y_distance;

/* USER CODE END PV */

void SystemClock_Config(void);
static void MX_GPIO_Init(void);
static void MX_DMA_Init(void);
static void MX_USART2_UART_Init(void);
static void MX_ADC1_Init(void);
static void MX_TIM1_Init(void);
static void MX_TIM2_Init(void);
static void MX_TIM3_Init(void);
static void MX_TIM4_Init(void);
static void MX_TIM5_Init(void);
static void MX_USART3_UART_Init(void);
static void MX_TIM14_Init(void);
static void MX_TIM13_Init(void);
static void MX_TIM11_Init(void);
/* USER CODE BEGIN 0 */
Profile x_profile;
Profile y_profile;
Profile W_profile;

Controller controller;

Motion motion;

//uint8_t rx_data;

uint8_t rxBuffer[2];
uint8_t rxIndex = 0;
float currentVelocity = DEFAULT_VELOCITY;
uint8_t commandReceived = 0;




/* USER CODE END 0 */

/**
  * @brief  The application entry point.
  * @retval int
  */
int main(void)
{

  /* MCU Configuration--------------------------------------------------------*/

  /* Reset of all peripherals, Initializes the Flash interface and the Systick. */
  HAL_Init();

  /* Configure the system clock */
  SystemClock_Config();

  /* Initialize all configured peripherals */
  MX_GPIO_Init();
  MX_DMA_Init();
  MX_USART2_UART_Init();
  MX_ADC1_Init();
  MX_TIM1_Init();
  MX_TIM2_Init();
  MX_TIM3_Init();
  MX_TIM4_Init();
  MX_TIM5_Init();
  MX_USART3_UART_Init();
  MX_TIM14_Init();
  MX_TIM13_Init();
  MX_TIM11_Init();
  /* USER CODE BEGIN 2 */
  HAL_TIM_PWM_Start(&htim1, TIM_CHANNEL_1);
  HAL_TIM_PWM_Start(&htim1, TIM_CHANNEL_2);
  HAL_TIM_PWM_Start(&htim1, TIM_CHANNEL_3);
  HAL_TIM_PWM_Start(&htim1, TIM_CHANNEL_4);

  HAL_TIM_Encoder_Start(&htim2, TIM_CHANNEL_ALL);
  HAL_TIM_Encoder_Start(&htim3, TIM_CHANNEL_ALL);
  HAL_TIM_Encoder_Start(&htim4, TIM_CHANNEL_ALL);
  HAL_TIM_Encoder_Start(&htim5, TIM_CHANNEL_ALL);

//  // Initialize kinematics system
//  init_kinematics();

  // Reset encoders
  resetEncoders();

  // Init BLuetooth Debug
  UART_Init(&huart2);

  // Start UART receive interrupt
  HAL_UART_Receive_IT(&huart3, &rxBuffer[rxIndex], 1);

  // Velocity timer
  HAL_TIM_Base_Start_IT(&htim14);
  HAL_TIM_Base_Start_IT(&htim13);
  HAL_TIM_Base_Start_IT(&htim11);

  HAL_GPIO_WritePin(Status_LED_GPIO_Port, Status_LED_Pin, 1);
  HAL_Delay(500);
  HAL_GPIO_WritePin(Status_LED_GPIO_Port, Status_LED_Pin, 0);
  HAL_Delay(500);

  Controller_Init(&controller);
  setTargetVelocities(0, 0, 0, 0);
  Profile_Reset(&x_profile);
  Profile_Reset(&y_profile);
  Profile_Reset(&W_profile);

  Motion_Init(&motion, &controller, &x_profile, &y_profile, &W_profile);
  Controller_ResetControllers(&controller);
  Motion_ResetDriveSystem(&motion);

  //HAL_Delay(5000);

//Profile_Move(&x_profile, 2, 0.25, 0, 0.05);
//  Profile_Move(&y_profile, 4, 0.6, 0, 0.05);
//Profile_Move(&W_profile, 4, 0.6, 0, 0.05);
//
//  Profile_Move(&x_profile, 0, 0, 0, 0);
//  Profile_Move(&y_profile, 0, 0, 0, 0);
//  Profile_Move(&W_profile, 0, 0, 0, 0);

  //Motion_X(&motion, 1);
 //Motion_Y(&motion, -1);
  //float val = (float)25 / 50.0f;
  //Motion_Y(&motion, val);
  //Motion_Diagonal_l(&motion, -1.414);
  //Motion_X(&motion, -1 * (float)50 / 50.0f);

  //HAL_Delay(1000);

  //HAL_UART_Receive_IT(&huart3, rx_data, 1);

  //TIM1->CCR1 = (uint32_t)3500;

//setForwardLeftMotorPWM(0.3);
//setForwardRightMotorPWM(0.6);
//setRearLeftMotorPWM(0.7);
//setRearRightMotorPWM(0.2);

// HAL_Delay(1000);
// //setTargetVelocities(3, 3, 3, 3);
//

//  set_robot_velocity(0.15, 0, 0);
//  HAL_Delay(3000);
//
//  set_robot_velocity(0.18, 0, 0);
//  HAL_Delay(2000);
//  set_robot_velocity(0.15, 0, 0);
//    HAL_Delay(3000);
//
//    set_robot_velocity(0.08, 0, 0);
//

// set_robot_velocity(0, 0, 0);
 //resetIntegralTerms();
  //int i = 0;
  //commandReceived = 1;
  /* USER CODE END 2 */

  /* Infinite loop */
  /* USER CODE BEGIN WHILE */
  while (1)
  {
	 //HAL_Delay(40);

    /* USER CODE END WHILE */

    /* USER CODE BEGIN 3 */
	//int cunt = getRearRightEncoderCounts();
	 //float current = 2.434;
	//UART_Transmit_Float(&huart2, "i", current, 2);
//    UART_Transmit_Int(&huart2, "S", i);
//    UART_Transmit_Int(&huart3, "S", i);
//    i++;
//    HAL_Delay(1000);
//	  SendTelemetryData();
	  if (commandReceived)
		{
			//UART_Transmit_Int(&huart2, "R", rxBuffer[0]);
			ExecuteCommand(rxBuffer[0], rxBuffer[1]);
		  //ExecuteCommand(1, 50);
			commandReceived = 0;
		}
	  //HAL_Delay(100);


	  //UART_Transmit_WheelW(&huart2, m1_W, m4_W, m2_W, m3_W);


  }
  /* USER CODE END 3 */
}

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
/* USER CODE BEGIN 4 */
ADC_HandleTypeDef* Get_HADC1_Ptr(void)
{
    return &hadc1;
}


void HAL_TIM_PeriodElapsedCallback(TIM_HandleTypeDef *htim){
	if(htim == &htim14){
		update_Encoder_Data();
		updateMotors();
		//updateMotors();
		//UART_Transmit_Int(&huart2, "S", HAL_GetTick());
	}
	else if(htim == &htim13){
		//UART_Transmit_Int(&huart2, "B", HAL_GetTick());

//		Profile_Update(&x_profile);
//		Profile_Update(&y_profile);
//		Profile_Update(&W_profile);
		Motion_Update(&motion);
//		UpdateControllers(&controller, Profile_GetSpeed(&x_profile), Profile_GetSpeed(&y_profile),  Profile_GetSpeed(&W_profile), 0);
		UpdateControllers(&controller, Motion_XVelocity(&motion), Motion_YVelocity(&motion),  Motion_Omega(&motion), 0);

	}
	else if(htim == &htim11){
		//Transmit Telemetry data
		//UART_Transmit_Int(&huart2, "T", HAL_GetTick());
		SendDistanceTelemetry(x_distance, y_distance);
	}
}
void HAL_UART_RxCpltCallback(UART_HandleTypeDef *huart)
{
	if (huart->Instance == USART3)
	    {
//		HAL_GPIO_TogglePin(LED_RX_GPIO_Port, LED_RX_Pin);
	        rxIndex++;
	        HAL_GPIO_WritePin(LED_RX_GPIO_Port, LED_RX_Pin, 1);

	        if (rxIndex >= 2)
	        {
	        	HAL_GPIO_WritePin(LED_RX_GPIO_Port, LED_RX_Pin, 0);
	            // Complete command received
	            commandReceived = 1;
	            rxIndex = 0;


	            // Echo back the received command

	            //HAL_UART_Transmit(&huart2, rxBuffer, 2, 100);

	        }

	        // Continue receiving
	        HAL_UART_Receive_IT(&huart3, &rxBuffer[rxIndex], 1);
	    }


//  if (huart == &huart3)
//  {
//    // Transmit received data via USART2
//
//
//    HAL_UART_Transmit(&huart2, rx_data, 1, HAL_MAX_DELAY);
//	//UART_Transmit_Int(&huart2, "RT", 69);
//
//    HAL_GPIO_TogglePin(Status_LED_GPIO_Port, Status_LED_Pin);
//
//    // Restart reception
//    HAL_UART_Receive_IT(&huart3, rx_data, 1);
//  }
}
/* USER CODE END 4 */
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


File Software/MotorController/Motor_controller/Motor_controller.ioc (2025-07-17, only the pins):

Mcu.UserName=STM32F446RETx
PA0-WKUP.GPIO_Label=M4_EncoderCH1
PA0-WKUP.Signal=S_TIM5_CH1
PA1.GPIO_Label=M4_EncoderCH2
PA1.Signal=S_TIM5_CH2
PA10.GPIO_Label=M3_PWM
PA10.Signal=S_TIM1_CH3
PA11.GPIO_Label=M4_PWM
PA11.Signal=S_TIM1_CH4
PA12.GPIO_Label=Status_LED
PA12.Signal=GPIO_Output
PA13.GPIO_Label=TMS
PA13.Signal=SYS_JTMS-SWDIO
PA14.GPIO_Label=TCK
PA14.Signal=SYS_JTCK-SWCLK
PA15.GPIO_Label=M1_EncoderCH1
PA15.Signal=S_TIM2_CH1_ETR
PA2.Signal=USART2_TX
PA3.Signal=USART2_RX
PA4.GPIO_Label=M1_CS
PA4.Signal=ADCx_IN4
PA5.GPIO_Label=M2_CS
PA5.Signal=ADCx_IN5
PA6.GPIO_Label=M3_CS
PA6.Signal=ADCx_IN6
PA7.GPIO_Label=M4_CS
PA7.Signal=ADCx_IN7
PA8.GPIO_Label=M1_PWM
PA8.Signal=S_TIM1_CH1
PA9.GPIO_Label=M2_PWM
PA9.Signal=S_TIM1_CH2
PB1.GPIO_Label=LED_RX
PB1.Signal=GPIO_Output
PB10.Signal=USART3_TX
PB2.GPIO_Label=LED_TX
PB2.Signal=GPIO_Output
PB3.GPIO_Label=M1_EncoderCH2
PB3.Signal=S_TIM2_CH2
PB4.GPIO_Label=M3_INA
PB4.Signal=GPIO_Output
PB5.GPIO_Label=M3_INB
PB5.Signal=GPIO_Output
PB6.GPIO_Label=M3_EncoderCH1
PB6.Signal=S_TIM4_CH1
PB7.GPIO_Label=M3_EncoderCH2
PB7.Signal=S_TIM4_CH2
PC10.GPIO_Label=M1_INA
PC10.Signal=GPIO_Output
PC11.GPIO_Label=M1_INB
PC11.Signal=GPIO_Output
PC14-OSC32_IN.Signal=RCC_OSC32_IN
PC15-OSC32_OUT.Signal=RCC_OSC32_OUT
PC2.GPIO_Label=M4_INA
PC2.Signal=GPIO_Output
PC3.GPIO_Label=M4_INB
PC3.Signal=GPIO_Output
PC4.GPIO_Label=TX_EN
PC4.Signal=GPIO_Output
PC5.Signal=USART3_RX
PC6.GPIO_Label=M2_EncoderCH1
PC6.Signal=S_TIM3_CH1
PC7.GPIO_Label=M2_EncoderCH2
PC7.Signal=S_TIM3_CH2
PC8.GPIO_Label=M2_INA
PC8.Signal=GPIO_Output
PC9.GPIO_Label=M2_INB
PC9.Signal=GPIO_Output
PH0-OSC_IN.Signal=RCC_OSC_IN
PH1-OSC_OUT.Signal=RCC_OSC_OUT

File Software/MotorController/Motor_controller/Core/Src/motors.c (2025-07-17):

/*
 * motors.c
 *
 *  Created on: May 10, 2025
 *      Author: PANKAJA
 */

#include "motors.h"
#include "config.h"
#include "bluetoothDebug.h"

uint16_t adc_buf[NUM_SAMPLES];
uint8_t complete = 0;

extern UART_HandleTypeDef huart2;



extern volatile WheelVelocities current_wheel_W;



volatile float m1_int = 0;
volatile float m2_int = 0;
volatile float m3_int = 0;
volatile float m4_int = 0;




float limitPWM(float pwm) {
    if (pwm > PWM_MAX)
        return PWM_MAX;
    else if (pwm < -PWM_MAX)
        return -PWM_MAX;
    return pwm;
}

void setForwardLeftMotorPWM(float pwm) {
    // Limit PWM value
    pwm = limitPWM(pwm);

    if (pwm >= 0) {
        // Forward direction: INA=0, INB=1
        // M1_INA = PC10, M1_INB = PC11
        // Reset bit 10 and Set bit 11 simultaneously
        GPIOC->BSRR = (1U << (10 + 16)) | (1U << 11);
        TIM1->CCR1 = (uint32_t)(pwm * MAX_TIMER_COUNTS);
    }
    else {
        // Reverse direction: INA=1, INB=0
        // Set bit 10 and Reset bit 11 simultaneously
        GPIOC->BSRR = (1U << 10) | (1U << (11 + 16));
        TIM1->CCR1 = (uint32_t)(-pwm * MAX_TIMER_COUNTS);
    }
}

void setForwardRightMotorPWM(float pwm) {
    // Limit PWM value
    pwm = limitPWM(pwm);

    if (pwm >= 0) {
        // Forward direction: INA=1, INB=0
        // M2_INA = PC8, M2_INB = PC9
        // Set bit 8 and Reset bit 9 simultaneously
        GPIOC->BSRR = (1U << 8) | (1U << (9 + 16));
        TIM1->CCR2 = (uint32_t)(pwm * MAX_TIMER_COUNTS);
    }
    else {
        // Reverse direction: INA=0, INB=1
        // Reset bit 8 and Set bit 9 simultaneously
        GPIOC->BSRR = (1U << (8 + 16)) | (1U << 9);
        TIM1->CCR2 = (uint32_t)(-pwm * MAX_TIMER_COUNTS);
    }
}

void setRearLeftMotorPWM(float pwm) {
    // Limit PWM value
    pwm = limitPWM(pwm);

    if (pwm >= 0) {
        // Forward direction: INA=0, INB=1
        // M3_INA = PB4, M3_INB = PB5
        // Reset bit 4 and Set bit 5 simultaneously
        GPIOB->BSRR = (1U << (4 + 16)) | (1U << 5);
    	//HAL_GPIO_WritePin(M3_INA_GPIO_Port, M3_INA_Pin, 0);
    	//HAL_GPIO_WritePin(M3_INB_GPIO_Port, M3_INB_Pin, 1);
        TIM1->CCR3 = (uint32_t)(pwm * MAX_TIMER_COUNTS);
    }
    else {
        // Reverse direction: INA=1, INB=0
        // Set bit 4 and Reset bit 5 simultaneously
        GPIOB->BSRR = (1U << 4) | (1U << (5 + 16));
    	//HAL_GPIO_WritePin(M3_INA_GPIO_Port, M3_INA_Pin, 1);
    	//HAL_GPIO_WritePin(M3_INB_GPIO_Port, M3_INB_Pin, 0);
        TIM1->CCR3 = (uint32_t)(-pwm * MAX_TIMER_COUNTS);
    }
}

void setRearRightMotorPWM(float pwm) {
    // Limit PWM value
    pwm = limitPWM(pwm);

    if (pwm >= 0) {
        // Forward direction: INA=1, INB=0
        // M4_INA = PC2, M4_INB = PC3
        // Set bit 2 and Reset bit 3 simultaneously
        GPIOC->BSRR = (1U << 2) | (1U << (3 + 16));
        TIM1->CCR4 = (uint32_t)(pwm * MAX_TIMER_COUNTS);
    }
    else {
        // Reverse direction: INA=0, INB=1
        // Reset bit 2 and Set bit 3 simultaneously
        GPIOC->BSRR = (1U << (2 + 16)) | (1U << 3);
        TIM1->CCR4 = (uint32_t)(-pwm * MAX_TIMER_COUNTS);
    }
}

void resetMotors(void) {
    // Stop all motors by setting PWM to 0
    TIM1->CCR1 = 0;
    TIM1->CCR2 = 0;
    TIM1->CCR3 = 0;
    TIM1->CCR4 = 0;

    // Set all control pins low simultaneously for each port
    // GPIOC: Reset M1_INA(PC10), M1_INB(PC11), M2_INA(PC8), M2_INB(PC9), M4_INA(PC2), M4_INB(PC3)
    GPIOC->BSRR = (1U << (10 + 16)) | (1U << (11 + 16)) |
                  (1U << (8 + 16)) | (1U << (9 + 16)) |
                  (1U << (2 + 16)) | (1U << (3 + 16));

    // GPIOB: Reset M3_INA(PB4), M3_INB(PB5)
    GPIOB->BSRR = (1U << (4 + 16)) | (1U << (5 + 16));
}


void updateMotors(){
    // Calculate velocity errors
	float m1_err = target_wheel_W.front_left - current_wheel_W.front_left;
	float m2_err = target_wheel_W.rear_left - current_wheel_W.rear_left;
	float m3_err = target_wheel_W.rear_right - current_wheel_W.rear_right;
	float m4_err = target_wheel_W.front_right - current_wheel_W.front_right;




    m1_int += m1_err * LOOP_INTERVAL;
    m2_int += m2_err * LOOP_INTERVAL;
    m3_int += m3_err * LOOP_INTERVAL;
    m4_int += m4_err * LOOP_INTERVAL;


    m1_int = clampf(m1_int, -MAXINTCLAMP, MAXINTCLAMP);
    m2_int = clampf(m2_int, -MAXINTCLAMP, MAXINTCLAMP);
    m3_int = clampf(m3_int, -MAXINTCLAMP, MAXINTCLAMP);
    m4_int = clampf(m4_int, -MAXINTCLAMP, MAXINTCLAMP);


    float m1_output = Kp_Vel * m1_err + Ki_Vel * m1_int;
    float m2_output = Kp_Vel * m2_err + Ki_Vel * m2_int;
    float m3_output = Kp_Vel * m3_err + Ki_Vel * m3_int;
    float m4_output = Kp_Vel * m4_err + Ki_Vel * m4_int;

    //  integral windup prevention
    // If output is saturated, reduce integral term
    if (m1_output > PWM_MAX) {
        m1_int -= (m1_output - PWM_MAX) / Ki_Vel;
        m1_output = PWM_MAX;
    } else if (m1_output < -PWM_MAX) {
        m1_int -= (m1_output + PWM_MAX) / Ki_Vel;
        m1_output = -PWM_MAX;
    }

    if (m2_output > PWM_MAX) {
        m2_int -= (m2_output - PWM_MAX) / Ki_Vel;
        m2_output = PWM_MAX;
    } else if (m2_output < -PWM_MAX) {
        m2_int -= (m2_output + PWM_MAX) / Ki_Vel;
        m2_output = -PWM_MAX;
    }

    if (m3_output > PWM_MAX) {
        m3_int -= (m3_output - PWM_MAX) / Ki_Vel;
        m3_output = PWM_MAX;
    } else if (m3_output < -PWM_MAX) {
        m3_int -= (m3_output + PWM_MAX) / Ki_Vel;
        m3_output = -PWM_MAX;
    }

    if (m4_output > PWM_MAX) {
        m4_int -= (m4_output - PWM_MAX) / Ki_Vel;
        m4_output = PWM_MAX;
    } else if (m4_output < -PWM_MAX) {
        m4_int -= (m4_output + PWM_MAX) / Ki_Vel;
        m4_output = -PWM_MAX;
    }


    setForwardLeftMotorPWM(m1_output);
    setForwardRightMotorPWM(m4_output);
    setRearLeftMotorPWM(m2_output);
    setRearRightMotorPWM(m3_output);
}


void resetIntegralTerms(void) {
    m1_int = 0;
    m2_int = 0;
    m3_int = 0;
    m4_int = 0;
}


void setTargetVelocities(float m1_target, float m2_target, float m3_target, float m4_target) {
	target_wheel_W.front_left = m1_target;
	target_wheel_W.rear_left = m2_target;
	target_wheel_W.rear_right = m3_target;
	target_wheel_W.front_right = m4_target;

}

void stopMotors(){
	setTargetVelocities(0, 0, 0,0);
	resetMotors();

	current_wheel_W.front_left = 0.0f;
	current_wheel_W.rear_left = 0.0f;
	current_wheel_W.rear_right = 0.0f;
	current_wheel_W.front_right = 0.0f;

	resetMotors();


}
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

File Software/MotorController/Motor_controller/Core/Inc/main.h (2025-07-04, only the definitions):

#define M4_INA_Pin GPIO_PIN_2
#define M4_INA_GPIO_Port GPIOC
#define M4_INB_Pin GPIO_PIN_3
#define M4_INB_GPIO_Port GPIOC
#define M4_EncoderCH1_Pin GPIO_PIN_0
#define M4_EncoderCH1_GPIO_Port GPIOA
#define M4_EncoderCH2_Pin GPIO_PIN_1
#define M4_EncoderCH2_GPIO_Port GPIOA
#define M1_CS_Pin GPIO_PIN_4
#define M1_CS_GPIO_Port GPIOA
#define M2_CS_Pin GPIO_PIN_5
#define M2_CS_GPIO_Port GPIOA
#define M3_CS_Pin GPIO_PIN_6
#define M3_CS_GPIO_Port GPIOA
#define M4_CS_Pin GPIO_PIN_7
#define M4_CS_GPIO_Port GPIOA
#define TX_EN_Pin GPIO_PIN_4
#define TX_EN_GPIO_Port GPIOC
#define LED_RX_Pin GPIO_PIN_1
#define LED_RX_GPIO_Port GPIOB
#define LED_TX_Pin GPIO_PIN_2
#define LED_TX_GPIO_Port GPIOB
#define M2_EncoderCH1_Pin GPIO_PIN_6
#define M2_EncoderCH1_GPIO_Port GPIOC
#define M2_EncoderCH2_Pin GPIO_PIN_7
#define M2_EncoderCH2_GPIO_Port GPIOC
#define M2_INA_Pin GPIO_PIN_8
#define M2_INA_GPIO_Port GPIOC
#define M2_INB_Pin GPIO_PIN_9
#define M2_INB_GPIO_Port GPIOC
#define M1_PWM_Pin GPIO_PIN_8
#define M1_PWM_GPIO_Port GPIOA
#define M2_PWM_Pin GPIO_PIN_9
#define M2_PWM_GPIO_Port GPIOA
#define M3_PWM_Pin GPIO_PIN_10
#define M3_PWM_GPIO_Port GPIOA
#define M4_PWM_Pin GPIO_PIN_11
#define M4_PWM_GPIO_Port GPIOA
#define Status_LED_Pin GPIO_PIN_12
#define Status_LED_GPIO_Port GPIOA
#define TMS_Pin GPIO_PIN_13
#define TMS_GPIO_Port GPIOA
#define TCK_Pin GPIO_PIN_14
#define TCK_GPIO_Port GPIOA
#define M1_EncoderCH1_Pin GPIO_PIN_15
#define M1_EncoderCH1_GPIO_Port GPIOA
#define M1_INA_Pin GPIO_PIN_10
#define M1_INA_GPIO_Port GPIOC
#define M1_INB_Pin GPIO_PIN_11
#define M1_INB_GPIO_Port GPIOC
#define M1_EncoderCH2_Pin GPIO_PIN_3
#define M1_EncoderCH2_GPIO_Port GPIOB
#define M3_INA_Pin GPIO_PIN_4
#define M3_INA_GPIO_Port GPIOB
#define M3_INB_Pin GPIO_PIN_5
#define M3_INB_GPIO_Port GPIOB
#define M3_EncoderCH1_Pin GPIO_PIN_6
#define M3_EncoderCH1_GPIO_Port GPIOB
#define M3_EncoderCH2_Pin GPIO_PIN_7
#define M3_EncoderCH2_GPIO_Port GPIOB

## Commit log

2025-02-24 Added Datasheets of Motor Controllers
    Added Datasheets of Motor Controllers that are being used in Industrial Robotics
2025-04-12 Motor controller PCB schematic init
    [Microcontroller.SchDoc, Motor_Controller.PrjPcb, Motor_Drivers.SchDoc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]
2025-04-25 Motor Controller Test code Init
    [Microcontroller.SchDoc, Motor_Controller.PrjPcb, Motor_Drivers.SchDoc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]
2025-04-25 initial motor controller demo code with fault detection and current monitoring in arduino
2025-04-25 Add initial Arduino Motor Driver demo code
2025-04-25 Nucleo Motor controller init
2025-04-26 Implement FIR Moving average filter to reduce noise in current measurement
    [main.c, motors.c, serial_oscilloscope.c]
2025-04-26 add reference material for Motor controller design
2025-04-28 stm32 design documents
2025-04-28 init pins for motor contoller
2025-05-21 Add PID controller implementation in pid.su
    - Introduced PID_Init, PID_Compute, PID_Reset, PID_SetSetpoint, and PID_SetTunings functions.
    - Each function is marked as static to limit its visibility to the current translation unit.
    - This addition enhances the motor control capabilities by implementing a PID control algorithm.
2025-05-21 Add Encoder calculations
    [wQEDAFRY Debug.cfg]
2025-05-22 First evalutaion motor controller code
2025-05-27 mechanical design by R_Osh
    [(24300)M3x6.SLDPRT, 1-1.step.SLDPRT, 1.SLDPRT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]
2025-06-01 Added Main PCB design files
    [Main PCB enclosure Top.SLDPRT, Main PCB enclosure.SLDASM]
2025-06-02 Kinematics implemetation
2025-07-04 Implemnted PID Controller for the motor controller
2025-07-04 Velocity profile implemetation
2025-07-06 Remove Motor Controller diagram from README.md
2025-07-07 X velocity Profile implemented
    [wQEDAFRY Debug.cfg]
2025-07-07 Create IMU enclosure
2025-07-07 Added IMU enclosure design files
    [IMU bottom.SLDPRT, IMU enclosure.SLDASM, IMU top.SLDPRT]
2025-07-08 added top plate design v2.0
    [Top plate assembly.SLDASM, Top_plate_v2.0.DXF, Top_plate_v2.0.SLDPRT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]
2025-07-10 Strafe Motion bug fixed
    [main.c, motors.c]
2025-07-10 destination button

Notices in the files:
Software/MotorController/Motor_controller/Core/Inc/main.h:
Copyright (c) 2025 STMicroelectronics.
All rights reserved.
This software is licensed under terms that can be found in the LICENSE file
